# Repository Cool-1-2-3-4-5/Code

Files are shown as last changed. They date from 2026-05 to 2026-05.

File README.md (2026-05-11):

# Smart Chess Bot

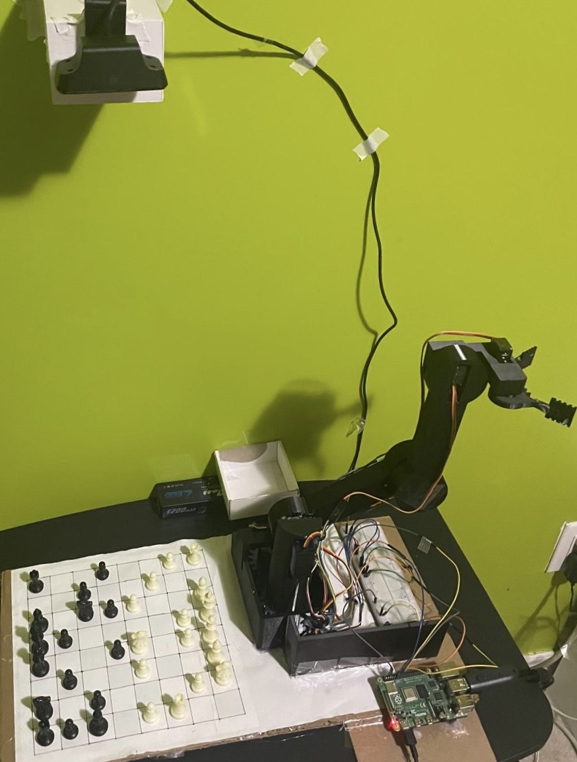
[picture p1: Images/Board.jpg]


SCB is a chess-playing robot that runs entirely on a Raspberry Pi 4. The robot plays white,
you play black. The Robot moves its own pieces using a 4-DOF robotic arm while you make
your moves on the real board.

---

## How It Works

The game starts by having you click the four corners of the chess board on the camera feed,
which sets up a perspective-warped top-down view using OpenCV. From there, the robot makes
the first move randomly and the game loop begins.

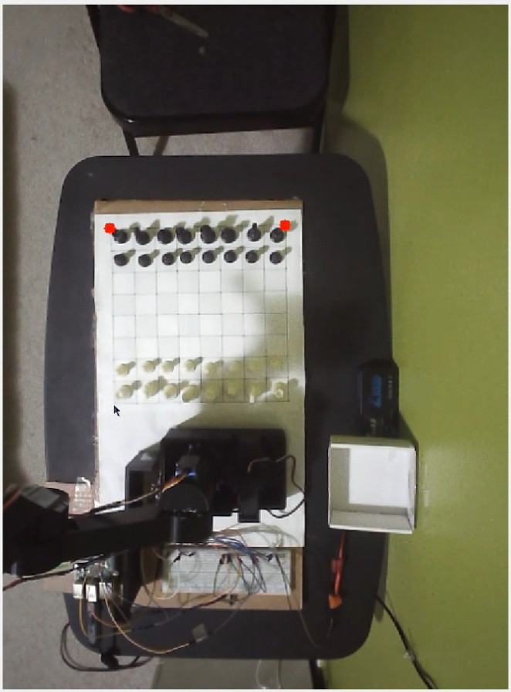
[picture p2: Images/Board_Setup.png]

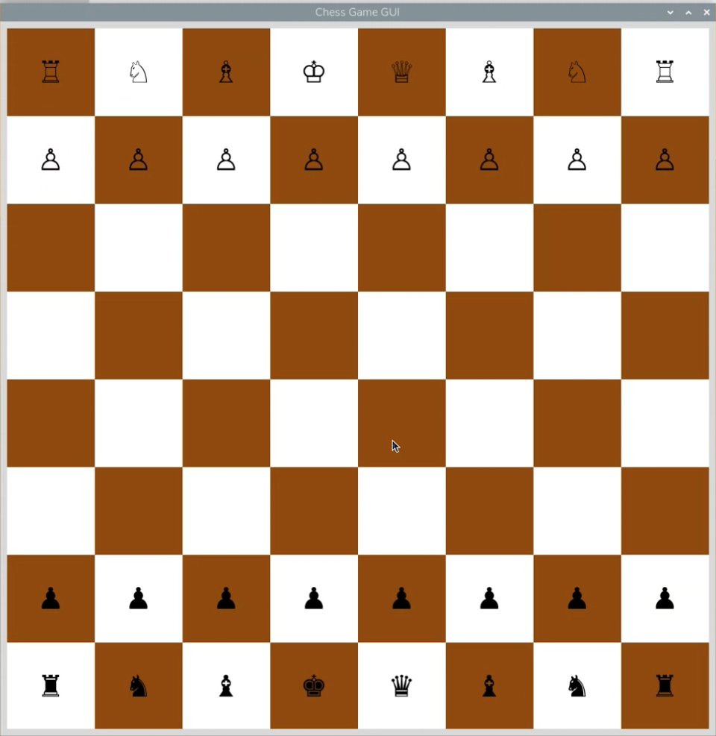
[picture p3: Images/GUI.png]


After each of your moves, you press spacebar to confirm. OpenCV captures the board, applies
thresholding and contour detection to locate all black pieces, and maps their pixel positions
to chess square coordinates (a1–h8). The previous and current board states are compared to
figure out what move you made, which is then validated against the legal move list before
being passed to the Minimax Algorithm.
The robot uses **Minimax with Alpha-Beta Pruning** to decide the best move (depth 5).
My minimax is slightly differnet than the typical minimax for a couple of reasons:
- The evaluation function factors in the **opponent mobility** alongside material score. If the move limits the the oppenents occupying sapce, it has a higher score
- **Checkmate is weighted by depth**, so checkmate in 1 scores better than checkmate in 3.
- Alpha-beta pruning keeps it efficient and able to calculate faster
- Function outputs the best move directly wihtout the need for a separate move tracker

Once the bot picks its move, the robotic arm executes it. Servo angles taken from a stored JSON lookup
table.
Each chess square has a pre-calculated set of servo angles derived from inverse kinematics. Given the physical
x, y, z measurements of every square relative to the arm's base, the joint angles are solved
geometrically using triangle relationships, then stored in a JSON lookup table.
This means at runtime the arm just reads the angles for the target square rather than solving
any math on the fly.

<p>
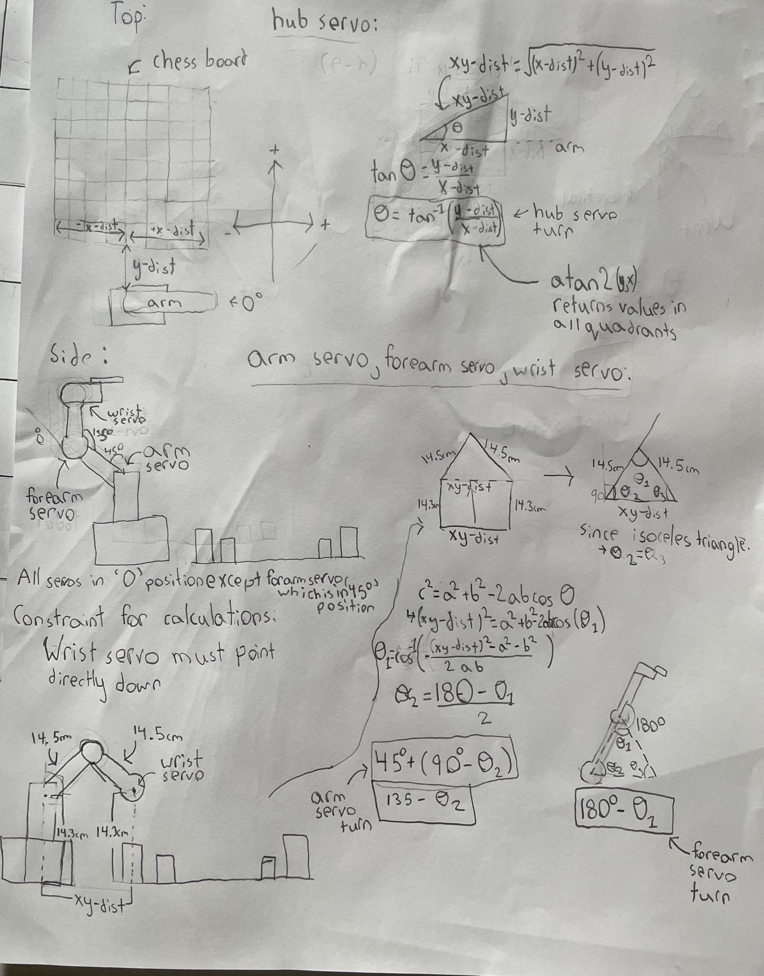
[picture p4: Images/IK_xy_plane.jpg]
  
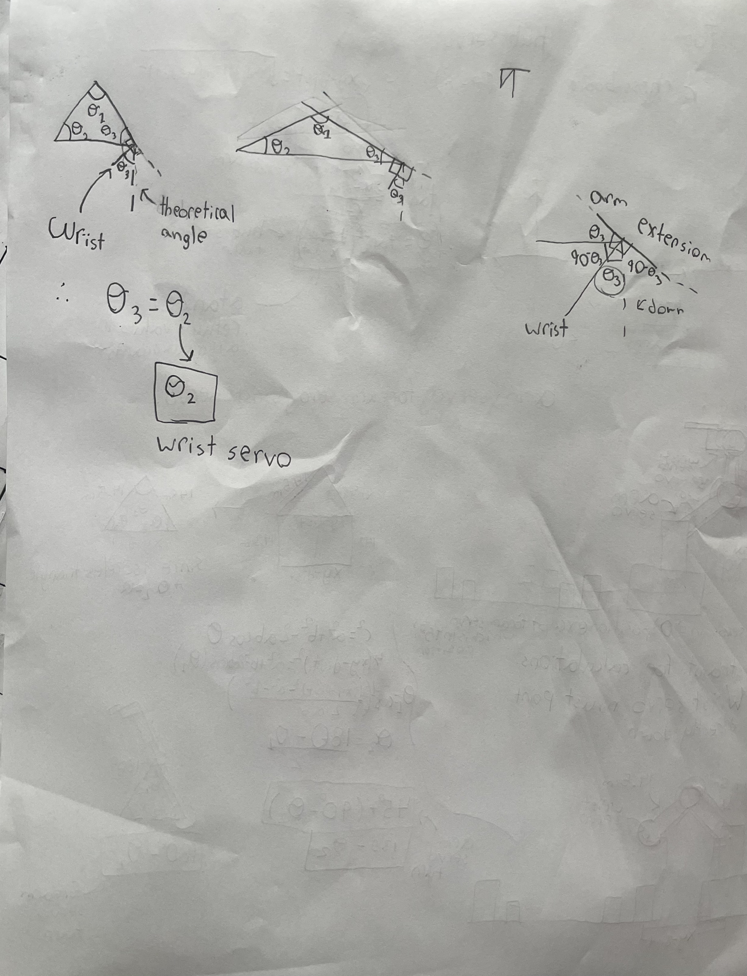
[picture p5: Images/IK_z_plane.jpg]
  
</p>

Threading is used to move joints simultaneously where needed.
Captures are handled separately: the arm picks up the opponent's piece first, drops it off the board, then moves
its own piece into the square.

---

## Computer Vision

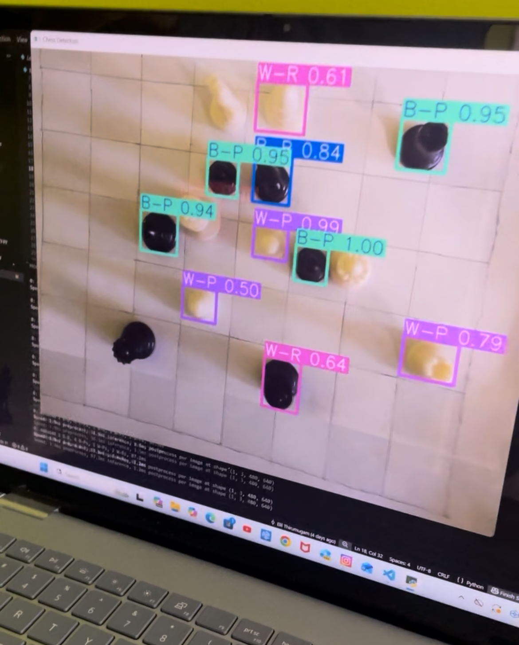
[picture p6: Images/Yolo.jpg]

I initially tried training a YOLOv8 model on ~250 labelled images to detect individual piece
types. It was only about 75% confident which is not reliable enough for a game logic
where a wrong detection breaks the whole game. I switched to a simpler thresholding +
contour detection approach, which turned out to be more consistent for this setup.

---

## Hardware and Components

All parts were designed in SolidWorks and 3D printed in PETG for strength. The arm has 5
degrees of freedom driven by two 20kg-cm servos and one 35kg-cm servo. All components runs on a
single Raspberry Pi 4, no separate microcontroller needed.

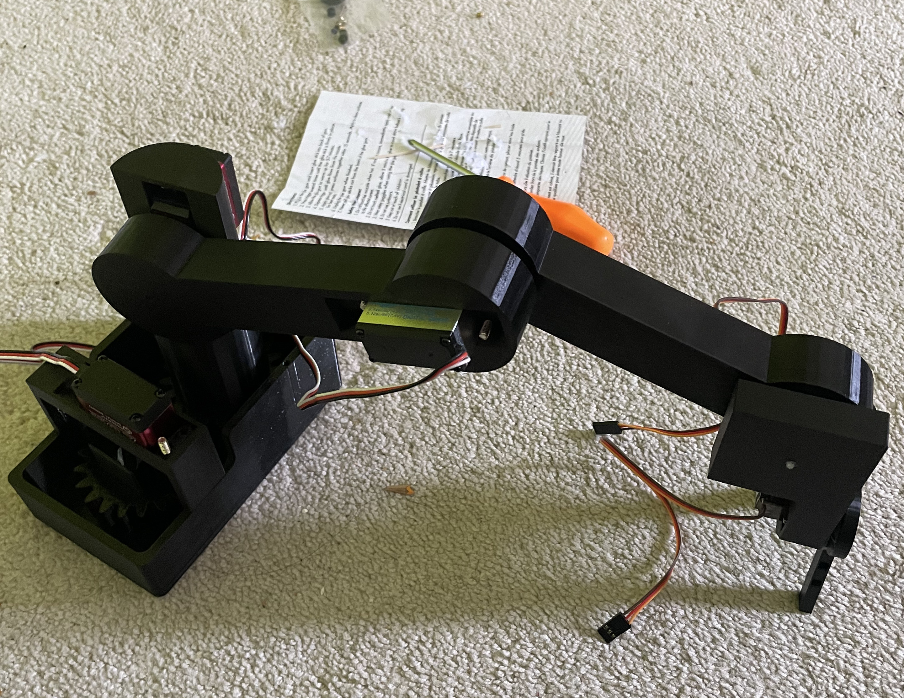
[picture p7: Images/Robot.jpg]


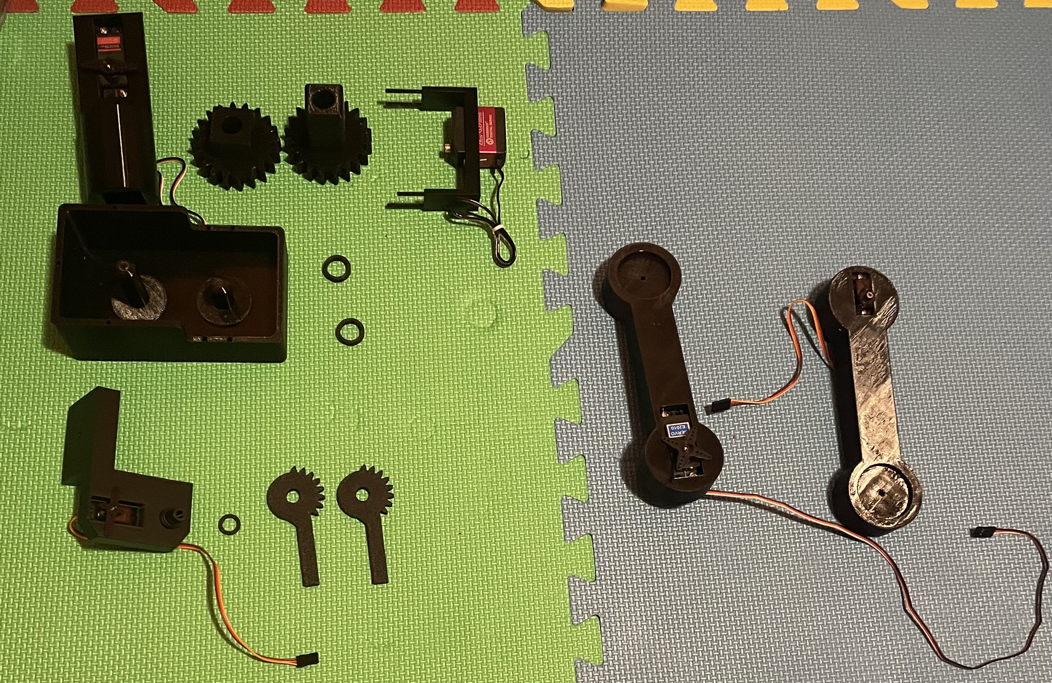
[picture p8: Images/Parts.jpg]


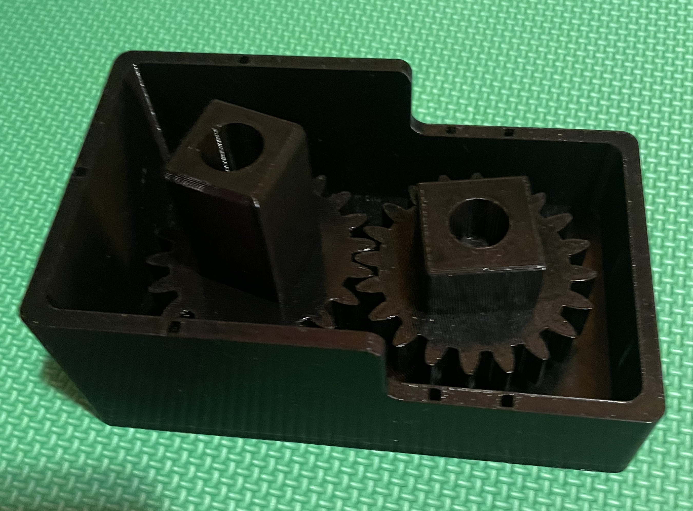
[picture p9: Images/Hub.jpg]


---

## Links

- [Website](https://cool-1-2-3-4-5.github.io/Personal-Website/)

- [YouTube Demo](https://youtu.be/Fy_8E9yMtNw?si=Ci3sZ67JCpUreh-P)

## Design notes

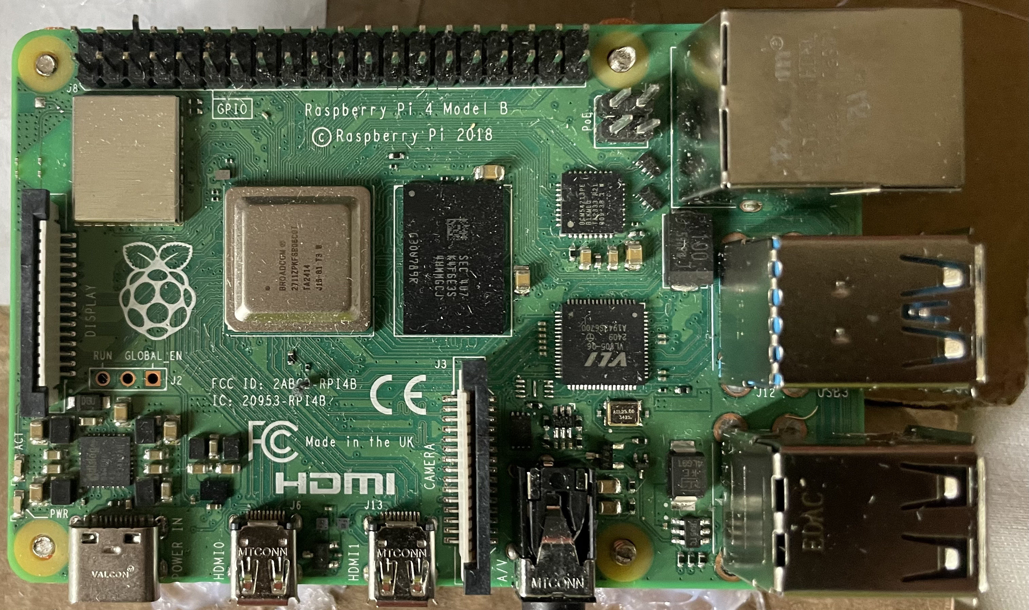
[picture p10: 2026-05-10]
Images/Pi.jpg

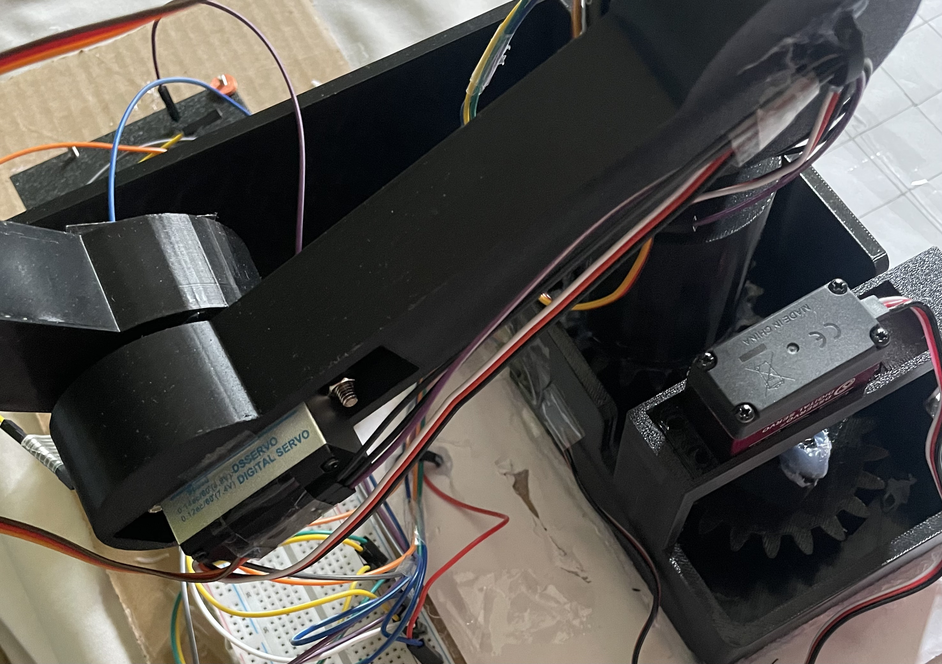
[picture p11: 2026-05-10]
Images/Motors.jpg

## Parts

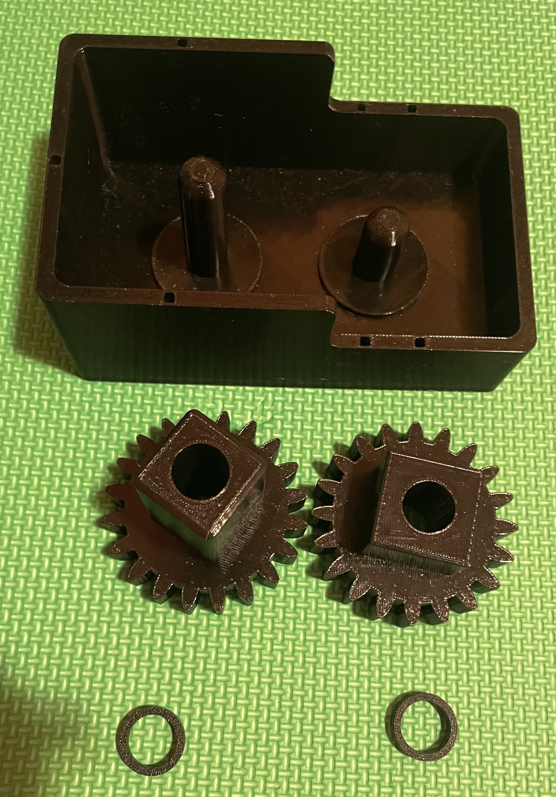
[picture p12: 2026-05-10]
Images/Hub_Parts.jpg

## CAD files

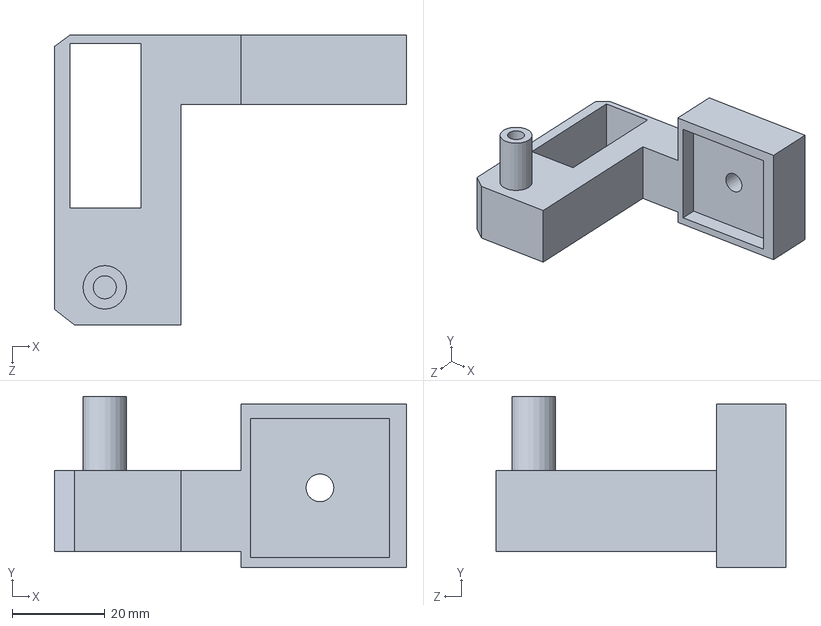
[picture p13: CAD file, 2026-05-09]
Parts/Grabber/Main_Piece.SLDPRT
75.9 x 37.0 x 62.5 mm

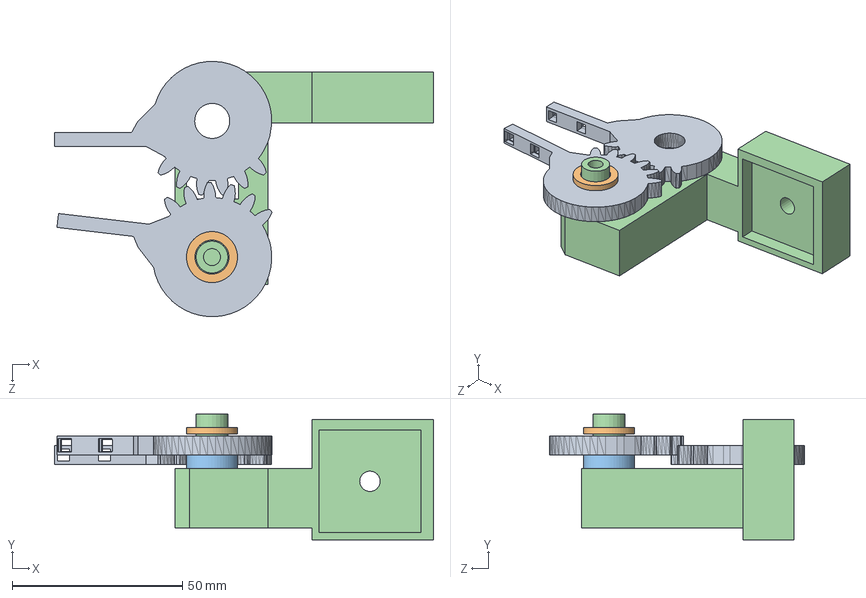
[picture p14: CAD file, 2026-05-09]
Assemblies/Grabber2.SLDASM
111.4 x 37.0 x 75.0 mm
Main_Piece
Spacer_Bottom
Spacer_Top
Grabber_Gear x 2

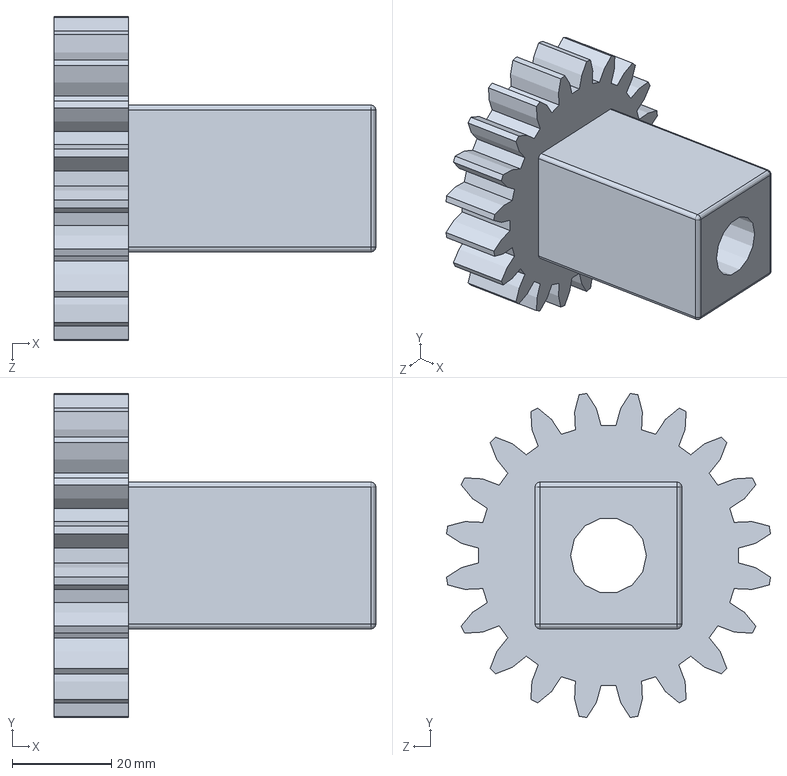
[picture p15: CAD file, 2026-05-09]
Parts/Hub/Spurgear_Servo_Attachment.SLDPRT
65.0 x 65.4 x 65.4 mm

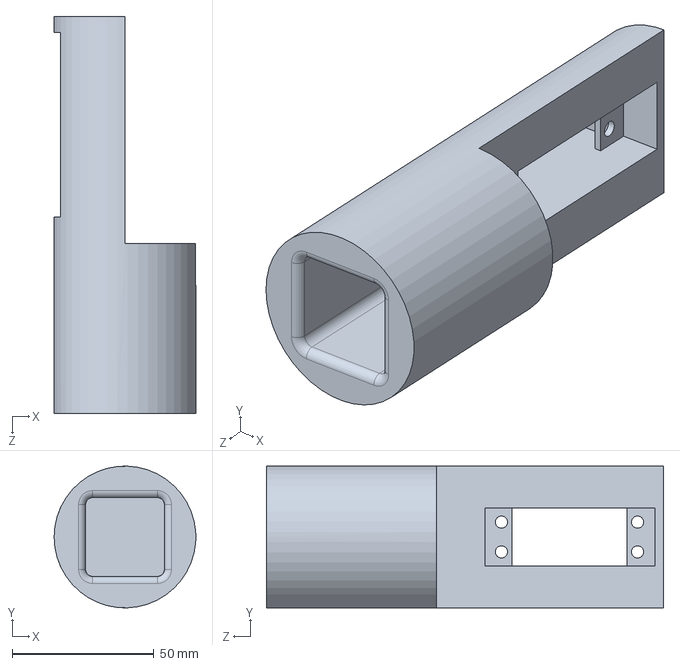
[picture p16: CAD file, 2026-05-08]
Parts/Main Arm/HubConnecter.SLDPRT
50.0 x 50.0 x 140.0 mm

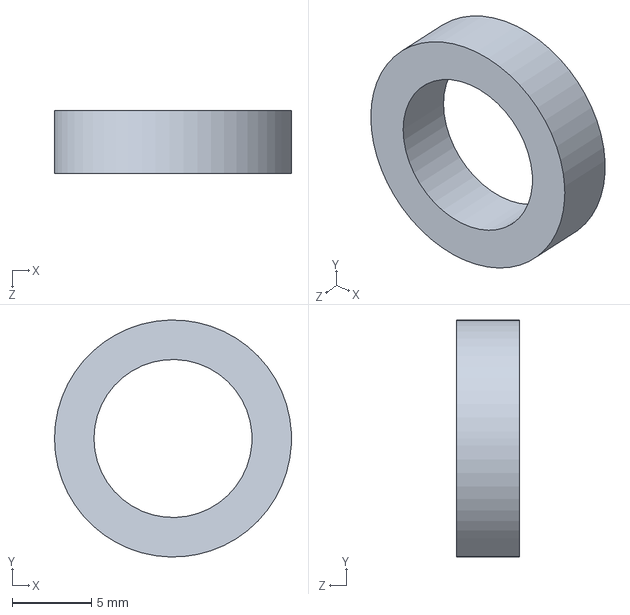
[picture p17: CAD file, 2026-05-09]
Parts/Grabber/Spacer_Bottom.SLDPRT
15.0 x 15.0 x 4.00 mm

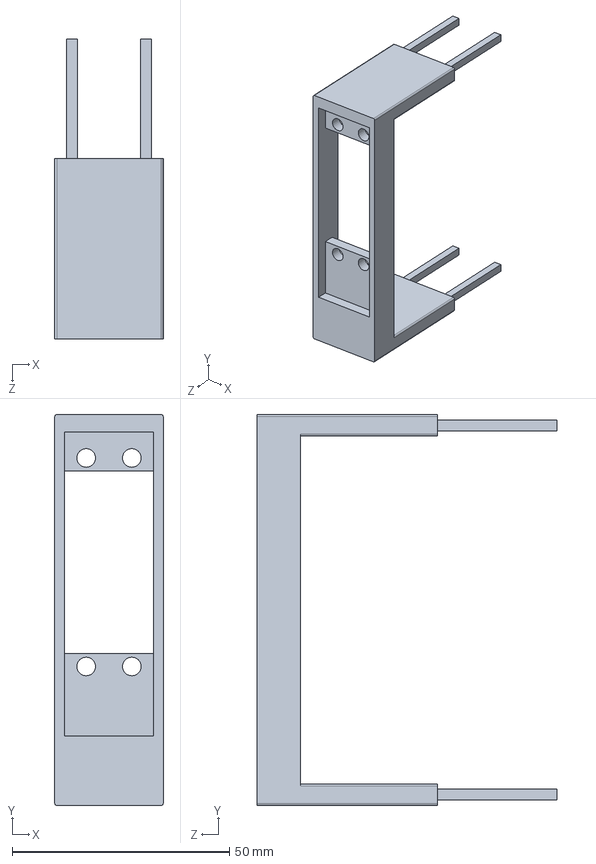
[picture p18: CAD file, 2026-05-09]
Parts/Hub/ServoHolder.SLDPRT
25.0 x 90.0 x 69.1 mm

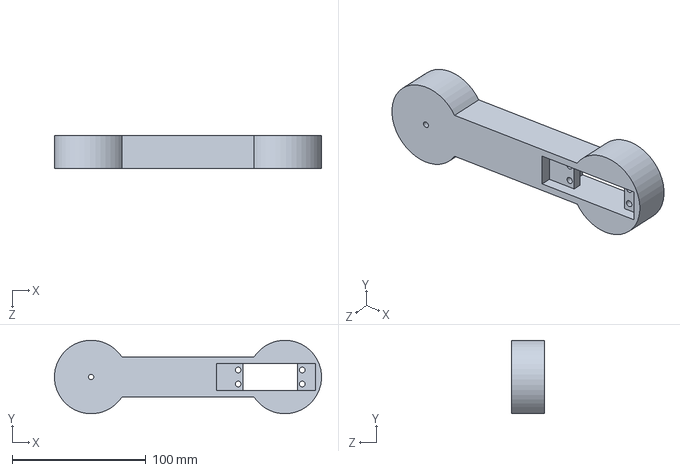
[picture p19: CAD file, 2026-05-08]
Parts/Main Arm/Shoulder.SLDPRT
199.9 x 55.0 x 25.0 mm

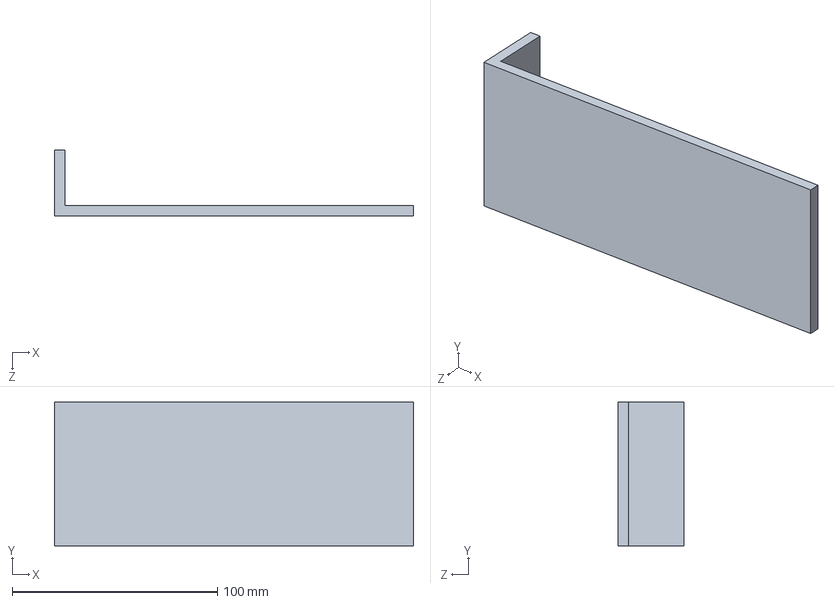
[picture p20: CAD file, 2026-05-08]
Parts/Divider.SLDPRT
175.0 x 70.0 x 32.0 mm

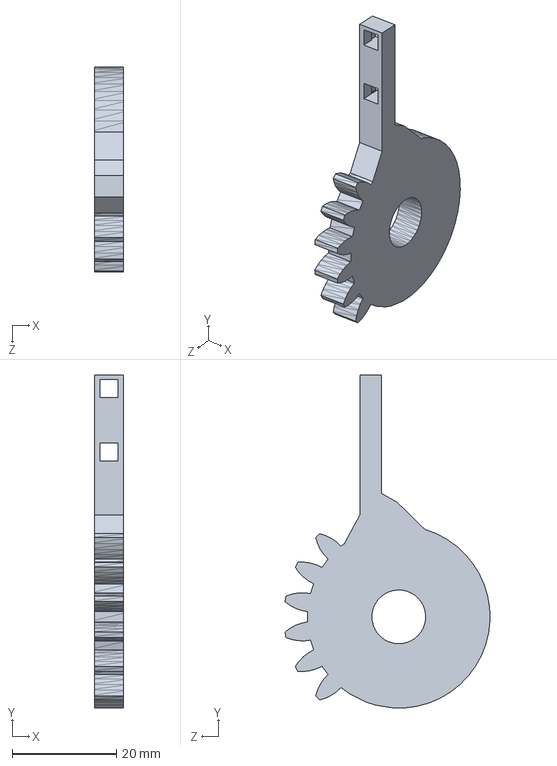
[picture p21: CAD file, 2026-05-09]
Parts/Grabber/Grabber_Gear.SLDPRT
5.60 x 63.8 x 39.3 mm

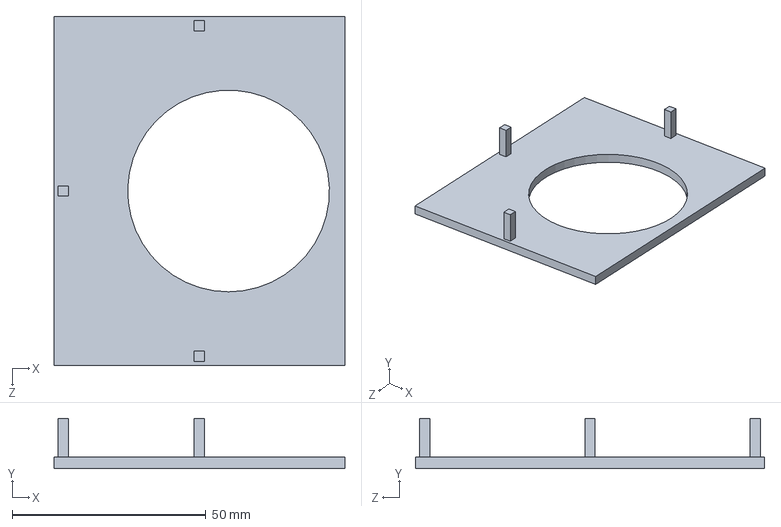
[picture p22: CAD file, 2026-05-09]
Parts/Hub/connecter_holder.SLDPRT
75.0 x 13.0 x 90.0 mm

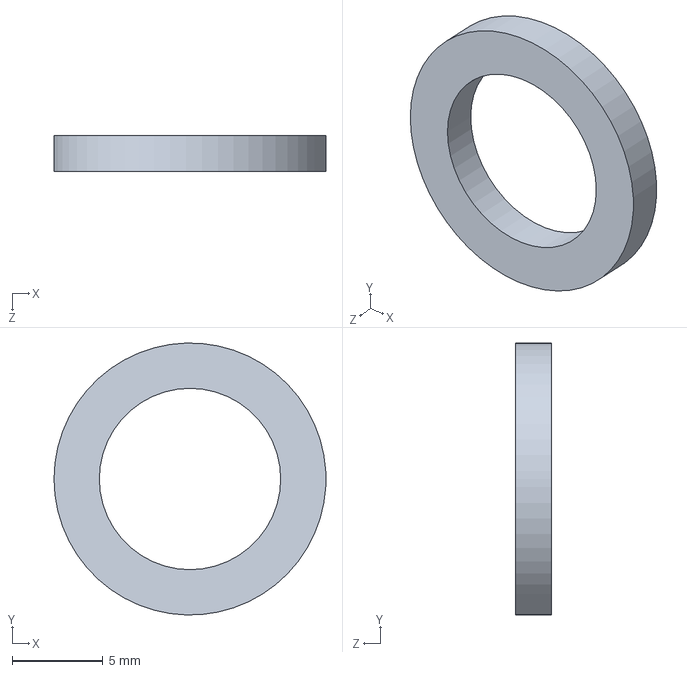
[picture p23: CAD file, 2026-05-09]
Parts/Grabber/Spacer_Top.SLDPRT
15.0 x 15.0 x 2.00 mm

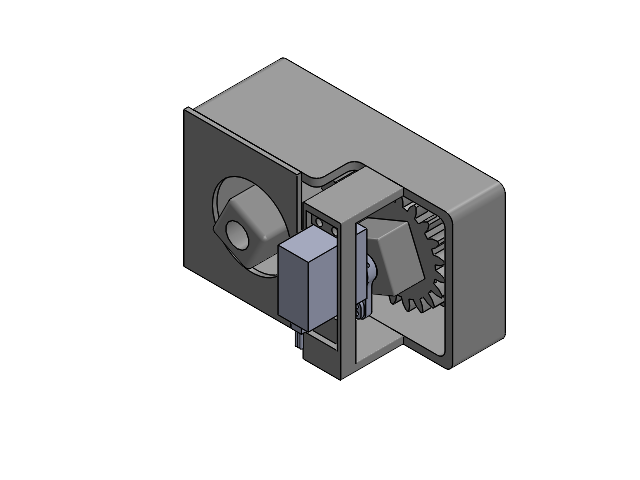
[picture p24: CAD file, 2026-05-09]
Assemblies/Hub.SLDASM
Hub_Frame
Hub_Spacer x 2
20KG Servo 6V-8.4V 180°.STEP
20KG Servo Arm.STEP
ServoHolder
connecter_holder
Spurgear_Servo
Spurgear_HubConnecter

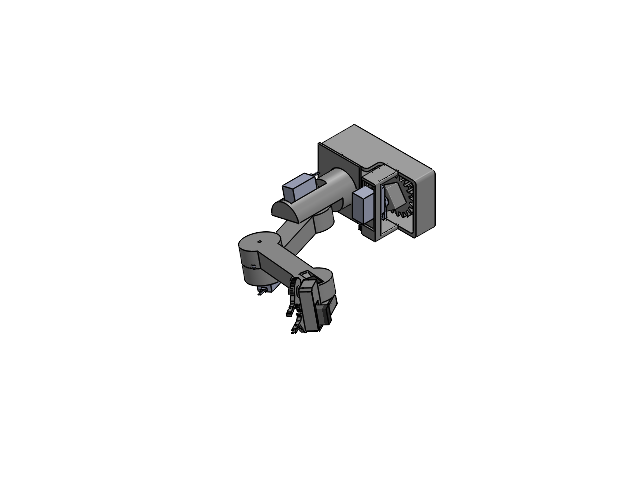
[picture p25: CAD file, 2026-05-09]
Main_Robot/Main_Robot.SLDASM
Hub_Frame
Hub_Spacer x 2
20KG Servo 6V-8.4V 180°.STEP x 3
20KG Servo Arm.STEP x 3
Spurgear_Servo
Spurgear_HubConnecter
ServoHolder
connecter_holder
Gripper_servo x 2
ForeArm
HubConnecter
Shoulder
Main_Piece
Spacer_Bottom
Spacer_Top
Part2^Grabber2
Grabber_Gear x 2

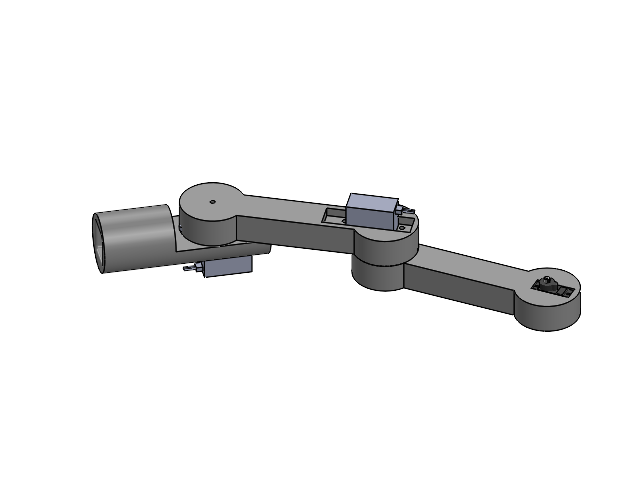
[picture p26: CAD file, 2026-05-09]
Assemblies/Main_Arm.SLDASM
20KG Servo 6V-8.4V 180°.STEP x 2
20KG Servo Arm.STEP x 2
Gripper_servo
ForeArm
HubConnecter
Shoulder

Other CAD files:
Parts/20KG Servo 6V-8.4V 180°+Arm.STEP.SLDASM
Parts/20KG Servo 6V-8.4V 180°.STEP.SLDPRT
Parts/Main Arm/ForeArm.SLDPRT
Parts/20KG Servo Arm.STEP.SLDPRT
Parts/Grabber/Grabber_Structure_joined.SLDPRT
Parts/Grabber/Small_Servo_Holder.SLDPRT
Parts/Gripper_servo.SLDPRT
Parts/Hub/Hub_Frame.SLDPRT
Parts/Hub/Hub_Spacer.SLDPRT
Parts/Hub/Spurgear_HubConnecter.SLDPRT
Parts/Hub/Spurgear_Servo.SLDPRT
Parts/Pi_Raise.SLDPRT

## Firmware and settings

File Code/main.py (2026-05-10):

import chess
from gpiozero import Device, AngularServo
from gpiozero.pins.pigpio import PiGPIOFactory
import tkinter as tk
Device.pin_factory = PiGPIOFactory() # (reduces servo jitter)
import cv2 as vision
from time import sleep
import random

import MovementFunctions
import ChessLibrary
import Learn
import View

shoulder = MovementFunctions.Mover(
    17,
    min_angle=0,
    max_angle=180,
    min_pulse_width= 0.7 / 1000,
    max_pulse_width= 2 / 1000
)

arm = MovementFunctions.Mover(
    27,
    min_angle=0,
    max_angle=180,
    min_pulse_width= 0.5 / 1000,
    max_pulse_width= 2.4 / 1000
)

forearm = MovementFunctions.Mover(
    22,
    min_angle=0,
    max_angle=180,
    min_pulse_width= 0.5 / 1000,
    max_pulse_width= 2.38 / 1000
)

wrist = MovementFunctions.Mover(
    23,
    min_angle=0,
    max_angle=180,
    min_pulse_width= 0.5 / 1000,
    max_pulse_width= 2.4 / 1000
)

gripper = MovementFunctions.Mover(
    24,
    min_angle=0,
    max_angle=180,
    min_pulse_width= 0.5 / 1000,
    max_pulse_width= 2.4 / 1000
)


# Chess Setup
prev_piece_locations = [
    'a8', 'b8', 'c8', 'd8', 'e8', 'f8', 'g8', 'h8',
    'a7', 'b7', 'c7', 'd7', 'e7', 'f7', 'g7', 'h7'
]
bot = chess.Board()
white_won = True
stalemate = False
crashcheck = False

# UI
root = tk.Tk()
root.title("Chess Game GUI")
gui = View.ChessboardUI(root, bot)

# Motor movements
MovementFunctions.servo_loader(shoulder,arm,forearm,wrist,gripper)
MovementFunctions.reset_angles()

# OpenCV Setup
cap = vision.VideoCapture(0)
cap.set(vision.CAP_PROP_FRAME_WIDTH, 480)
cap.set(vision.CAP_PROP_FRAME_HEIGHT, 480)

gui.write("Welcome to the Robot vs Human\nChess Board Game! White to go\nfirst. Once turn is done press\n'space bar' to confirms your move","start",6,45)
gui.write("First set up the board! Enter\nthe four corners of the chess\nboard in any order to continue","setup",3,50)
main = Learn.board_setup(cap)
vision.destroyAllWindows()

# GAME LOGIC

# Game Opener
gui.write("Great!\nLETS START THE GAME\nIN 5 SECONDS","second_start",5,50)
gui.write("LETS BEGIN!","third_start",2,80)
gui.setboard()
gui.root.update()
gui.delay(2)

# GAME LOOP

# Robot goes first (Robot is White)
legal_moves = list(gui.chess_logic.legal_moves)
random_index = random.randint(0, len(legal_moves) - 1)
random_move = legal_moves[random_index]
gui.chess_logic.push(random_move)
gui.update_board()
MovementFunctions.robotTurnToPlay("Regular", str(random_move.uci()))


# Black and white flip-flop (Robot is White, user is black)
while not gui.chess_logic.is_checkmate() and not gui.chess_logic.is_stalemate():
    # BLACK Turn
    updated_piece_locations = []
    bestMove_in_UCI = ''
    bestMove_in_SAN = ''
    move_type = ''
    
    # Wait till user is done playing their move
    gui.root.bind('<space>',gui.pressed)
    gui.state = False
    while not gui.state:
        gui.root.update()
    
    # Return locations (x,y) of black pieces and evalute at what squares there is a piece
    locations = Learn.board_update(cap, main)
    vision.destroyAllWindows()
    setup = []
    if locations:
        for mid in locations:
            location = Learn.piece_in_square(mid)
            if location is not None:
                if location not in setup:
                    setup.append(location)    

        # Determining chess piece squares based on (x,y) of pieces
        user_move_in_UCI = Learn.eval_board(prev_piece_locations,setup)
        prev_piece_locations = setup.copy()
        if chess.Move.from_uci(user_move_in_UCI) in gui.chess_logic.legal_moves:
            gui.chess_logic.push_uci(user_move_in_UCI)
            gui.update_board()
            gui.root.update()
            if gui.chess_logic.is_check():
                gui.write("White in Check\n","Check",2,50,True)
                gui.root.update()

            # WHITE Turn

            # Robot calculated move
            if not gui.chess_logic.is_checkmate() and not gui.chess_logic.is_stalemate():
                bestMove_in_UCI, bestMove_in_SAN = ChessLibrary.minimax(gui.chess_logic, gui.chess_logic.legal_moves,5,True,-100000,100000,True)

                # Find if best move captures or just moves piece
                if 'x' in bestMove_in_SAN: #Capture
                    move_type = "Piece_Won"
                    remove_move = str(bestMove_in_UCI[-2]) + str(bestMove_in_UCI[-1])
                    prev_piece_locations.remove(remove_move)
                else:
                    move_type = "Regular"

                # movement control: Run Robot movement
                #ADD SERVOS
                MovementFunctions.robotTurnToPlay(move_type,bestMove_in_UCI)
                gui.chess_logic.push_san(bestMove_in_SAN)
                gui.update_board()
                if gui.chess_logic.is_check():
                    gui.write("Black in Check\n","Check",2,50,True)
                    gui.root.update()
            elif gui.chess_logic.is_checkmate():  #Black Won
                white_won = False
            else:
                stalemate = True
        else:
            gui.clear_text("all")
            gui.delay(1)
            gui.write("Not Valid move, program crashed","Issue",5,50)
            crashcheck = True
            break
    else:
        gui.clear_text("all")
        gui.delay(1)
        gui.write("Error with Camera Viewing","Issue",5,50)
        crashcheck = True
        break

if not crashcheck:
    if gui.chess_logic.is_stalemate():
        stalemate = True
    gui.clear_text("all")
    gui.delay(1)
    if stalemate:
        text = "Stalemate!\nPlease Play Again!"
    elif white_won:
        text = "Robot has won!\nPlease Play Again!"
    else:
        text = "Human has won!\nPlease Play Again!"
    gui.write(text,"Who_won",5,50)
gui.delay(3)
cap.release()
vision.destroyAllWindows()

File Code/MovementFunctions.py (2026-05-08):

from gpiozero import Device, AngularServo
from gpiozero.pins.pigpio import PiGPIOFactory
from time import sleep
from concurrent.futures import ThreadPoolExecutor
import json

Device.pin_factory = PiGPIOFactory()

with open('inversekinematics.json', 'r') as f:
    data = json.load(f)

hub = None
arm = None
forearm = None
wrist = None
gripper = None

class Mover(AngularServo):
    def set_angle(self,degrees,step_size=0.3, delay=0.01):
        if self.angle is not None:
            current_angle = self.angle
        else:
            current_angle = 90

        if current_angle < degrees:
            while current_angle < degrees:
                current_angle = min(current_angle + step_size, degrees)
                self.angle = current_angle
                sleep(delay)
        else:
            while current_angle > degrees:
                current_angle = max(current_angle - step_size, degrees)
                self.angle = current_angle
                sleep(delay)

def servo_loader(main_hub,main_arm,main_forearm,main_wrist,main_gripper):
    global hub
    hub = main_hub
    global arm
    arm = main_arm
    global forearm
    forearm = main_forearm
    global wrist
    wrist = main_wrist
    global gripper
    gripper = main_gripper

def reset_angles(hub_angle=0):
    hub.set_angle(hub_angle)
    arm.set_angle(0)
    forearm.set_angle(45)
    wrist.set_angle(180)
    gripper.set_angle(0)

def end_angle():
    hub.set_angle(0)
    arm.set_angle(0)
    forearm.set_angle(0)
    wrist.set_angle(0)
    gripper.set_angle(0)


def move_arm_with_wrist(angle):
    with ThreadPoolExecutor(max_workers=2) as executor:
        executor.submit(arm.set_angle, arm.angle + angle)
        executor.submit(wrist.set_angle, wrist.angle + angle)

def move_across(arm_angle, forearm_angle):
    with ThreadPoolExecutor(max_workers=2) as executor:
        executor.submit(arm.set_angle, arm_angle)
        executor.submit(forearm.set_angle, forearm_angle)

def regular_move(move,interval=0.8):
    first_half = move[0] + move[1]
    positions = data[first_half]

    # first set
    hub.set_angle(positions[0])
    sleep(interval)
    move_across(positions[1],positions[2])
    wrist.set_angle(positions[3])
    sleep(interval+1)
    gripper.set_angle(35)
    sleep(interval+1)
    
    
    #Go down
    move_arm_with_wrist(positions[4])
    sleep(interval)
    
    gripper.set_angle(49)
    sleep(interval)

    #Go Up
    move_arm_with_wrist(-1 * positions[4])
    sleep(interval)

    arm.set_angle(positions[1]-20)
    sleep(interval)

    second_half = move[2] + move[3]

    positions2 = data[second_half]
    
    # Go to next square:

    move_across(positions2[1],positions2[2])
    sleep(interval)

    # second set
    hub.set_angle(positions2[0])
    sleep(interval)
    wrist.set_angle(positions2[3])
    sleep(interval)

    #Go down
    move_arm_with_wrist(positions2[4])
    sleep(interval)
    
    gripper.set_angle(37)
    sleep(interval)

    #Going up
    move_arm_with_wrist(-1 * (positions2[4]+10))
    sleep(interval)
    wrist.set_angle(90)
    sleep(interval)
    
    reset_angles(90)
    sleep(interval)



def capture_move(move,interval=0.5):
    first_half = move[-2] + move[-1]
    positions = data[first_half]

    # first set
    hub.set_angle(positions[0])
    sleep(interval)
    move_across(positions[1]+3,positions[2]+3)
    sleep(0.2)
    move_across(positions[1],positions[2])
    sleep(interval)
    wrist.set_angle(positions[3])
    sleep(interval)
    gripper.set_angle(37)
    sleep(interval)
    
    #Go down
    move_arm_with_wrist(positions[4])
    sleep(interval)
    
    gripper.set_angle(46)
    sleep(interval)

    #Go Up
    move_arm_with_wrist(-1 * positions[4])
    sleep(interval)

    arm.set_angle(positions[1]-20)
    sleep(interval)

    # Drop Piece
    drop_piece()
    # Next Square
    second_half = move[0] + move[1]

    positions2 = data[second_half]
    # reset_angles(positions2[0])
    # sleep(interval)
    # Go to next square:
    
    hub.set_angle(positions2[0])
    sleep(interval)
    move_across(positions2[1]+3,positions2[2]+3)
    sleep(0.2)
    move_across(positions2[1],positions2[2])
    sleep(interval)
    wrist.set_angle(positions2[3])
    sleep(interval)
    gripper.set_angle(37)
    sleep(interval)

    #Go down
    move_arm_with_wrist(positions2[4])
    sleep(interval)
    print("here")
    gripper.set_angle(46)
    sleep(interval)
    
    #Going up
    move_arm_with_wrist(-1 * positions2[4])
    sleep(interval)
    print("heraae")
    arm.set_angle(positions2[1]-20)
    sleep(interval)

    # Place piece
    hub.set_angle(positions[0])
    sleep(interval)
    move_across(positions[1],positions[2])
    sleep(interval)
    wrist.set_angle(positions[3])
    sleep(interval+1)    
    
    #Go down
    move_arm_with_wrist(positions[4])
    sleep(interval)
    
    gripper.set_angle(37)
    sleep(interval)

    #Go Up
    move_arm_with_wrist(-1 * (positions[4]+10))
    sleep(interval)

    arm.set_angle(positions[1]-20)
    sleep(interval)
    
    wrist.set_angle(90)
    sleep(interval)

    reset_angles(90)
    sleep(interval)

def drop_piece(interval=0.5):
    arm.set_angle(60)
    sleep(interval)
    forearm.set_angle(90)
    sleep(interval)
    hub.set_angle(0)
    sleep(interval)
    wrist.set_angle(15)
    sleep(interval)
    gripper.set_angle(0)
    sleep(interval)

def resting(interval=0.5):
    arm.set_angle(90)
    sleep(interval)
    forearm.set_angle(0)
    sleep(interval)
    wrist.set_angle(80)
    sleep(interval)
    hub.set_angle(0)
    sleep(interval)
    gripper.set_angle(0)
    sleep(interval)

def robotTurnToPlay(move_type, move, interval=0.5):
    if move_type == "Piece_Won":
        capture_move(move,interval)
    else:
        regular_move(move,interval)

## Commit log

2026-02-18 need to work on camera ca;ibration
2026-03-04 Added comments and rotated camera
2026-03-09 Pi works with servo
2026-03-15 motor functions complete
2026-03-21 Added PIGZERO and Smooth servo movement
2026-03-26 Testing servo connections
2026-03-27 made changesd to speed of servos
2026-03-27 testing camera integration
2026-03-29 servos attached
2026-03-29 servo movement fixed
2026-04-01 edits to functions to prevent jitter
2026-04-15 37-35 for gripper
2026-04-16 flow changed
2026-04-28 updated rezied frame
2026-04-30 Issues with eval function fixed
    [Learn.py, main.py]
2026-04-30 inverse kinematics issues
2026-05-01 added stalemate print
2026-05-08 restore CAD assemblies and parts folders
    [20KG Servo 6V-8.4V 180°+Arm.STEP.SLDASM, 20KG Servo 6V-8.4V 180°.STEP.SLDPRT, 20KG Servo Arm.STEP.SLDPRT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]
2026-05-08 remove unnecessary CAD files
    [20KG Servo 6V-8.4V 180°+Arm.STEP.SLDASM, 20KG Servo 6V-8.4V 180°.STEP.SLDPRT, 20KG Servo Arm.STEP.SLDPRT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]
2026-05-09 Cleaned up Assemblies
    [Grabber2.SLDASM, Grabber_Gear.SLDPRT, Hub.SLDASM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]
2026-05-09 cleaned up comments
    [Hub.SLDASM, Spurgear_Servo_Attachment.SLDPRT]
